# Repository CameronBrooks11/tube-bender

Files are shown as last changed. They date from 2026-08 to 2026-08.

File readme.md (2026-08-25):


# Tube-bender
A parametric manual rotary-draw tube bender, from 1/8 in to 2 in outside diameter.

The machine is the swing-arm pattern that J D Squared and Pro-Tools have sold for
decades: a grooved forming die on a centre pivot, a U-strap clamping the tube to it, a
followbar reacting the bending load, and a drive link that rotates the die from a
handle. What is new here is that it is derived rather than drawn - the die comes from
the tube, the pins come from the loads they carry, and the base bolt pattern comes from
the torque it has to react.

Every part of the working mechanism is built and derived: the forming die - machined
from one plate or stacked from flat-cut slices, behind the same interface - its plates,
the clamp, the followbar, the tapered frame and drive links, the die lock that holds the
die against springback between strokes, and a bench base or a pedestal.

## Driving it

Open this file in OpenSCAD and use the **Customizer** (Window > Customizer). Everything
that decides what the machine is has a control there: the tube, the bend, the plate
stock, the die style, the mounting, and which part to look at. `tube_bender.json` beside
this file carries a few worked configurations to start from, including the 1-1/2 in
prototype and a sliced-die build for a shop with no mill.

The **Units** tab switches the report and the BOM between metric and imperial as a
whole system - length, force, moment, stress and mass together, because inches with
newtons is harder to check than either on its own. It changes nothing that is
calculated, and it changes no name: a tube is "1-1/2 in OD x 0.095 in wall" and plate is
ordered as "1/4 in" in both.

Nothing in the Customizer is a dimension of a part. Every part is derived from the tube
and the loads, so choosing a 1 in tube resizes the die, the pins, the links, the base
and the handle together - and the arithmetic behind that is echoed rather than hidden.
`just report` prints it, or read the console after any render.

## Two words in the parts list that are NopSCADlib's, not ours

Nothing here is printed. The list has a **"3D printed parts"** heading because that is
what NopSCADlib calls a part you make rather than buy, and under it are the three parts
with real depth to cut - the forming die, the clamp and the followbar - which are
**machined**. Everything flat is under **"CNC routed"**, which is right: those go to a
laser, waterjet or plasma table as the DXF files linked beside them.

Why the numbers are what they are, and what each one rests on, is in
[docs/design-basis.md](docs/design-basis.md). What the Onshape prototype this was
started from actually measured, and which of its features survived, is in
[docs/reverse-engineering.md](docs/reverse-engineering.md).

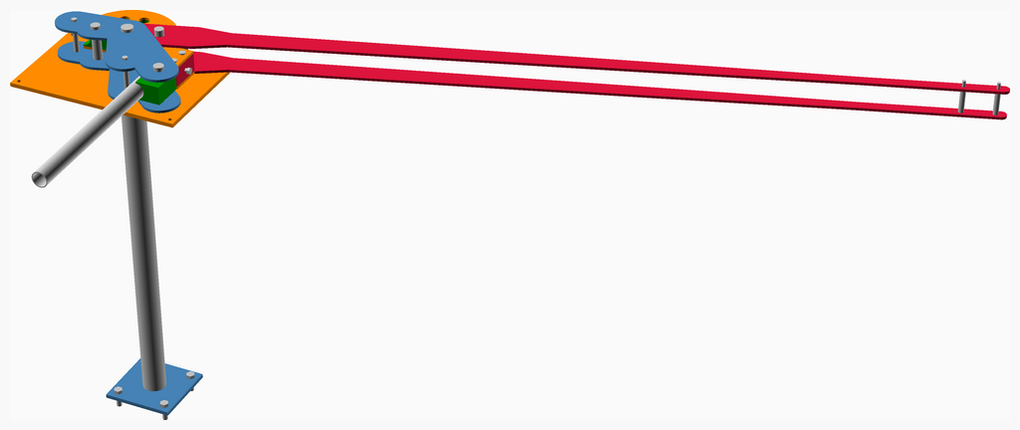
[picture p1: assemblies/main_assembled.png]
Main Assembly


<span></span>

---
## Table of Contents
1. [Parts list](#Parts_list)
1. [Base Assembly](#base_assembly)
1. [Die Assembly](#die_assembly)
1. [Handle Assembly](#handle_assembly)
1. [Main Assembly](#main_assembly)

<span></span>
[Top](#TOP)

---

## Parts list
| <span style="writing-mode: vertical-rl; text-orientation: mixed;">Base</span> | <span style="writing-mode: vertical-rl; text-orientation: mixed;">Die</span> | <span style="writing-mode: vertical-rl; text-orientation: mixed;">Handle</span> | <span style="writing-mode: vertical-rl; text-orientation: mixed;">Main</span> | <span style="writing-mode: vertical-rl; text-orientation: mixed;">TOTALS</span> |  |
|---:|---:|---:|---:|---:|:---|
|  |  |  |  | | **Vitamins** |
| &nbsp;&nbsp;.&nbsp; | &nbsp;&nbsp;.&nbsp; | &nbsp;&nbsp;.&nbsp; | &nbsp;&nbsp;4&nbsp; |  &nbsp;&nbsp;4&nbsp; | &nbsp;&nbsp; Bolt hex head 1/2 in x 44.45 mm, with nut and washers, NO ORDER NUMBER - this row is a hole in the BOM |
| &nbsp;&nbsp;.&nbsp; | &nbsp;&nbsp;.&nbsp; | &nbsp;&nbsp;.&nbsp; | &nbsp;&nbsp;1&nbsp; |  &nbsp;&nbsp;1&nbsp; | &nbsp;&nbsp; Bolt hex head 3/8 in x 38.1 mm, with nut and washers, NO ORDER NUMBER - this row is a hole in the BOM |
| &nbsp;&nbsp;.&nbsp; | &nbsp;&nbsp;6&nbsp; | &nbsp;&nbsp;.&nbsp; | &nbsp;&nbsp;.&nbsp; |  &nbsp;&nbsp;6&nbsp; | &nbsp;&nbsp; Bolt hex head 3/8 in x 57.15 mm, with nut and washers, NO ORDER NUMBER - this row is a hole in the BOM |
| &nbsp;&nbsp;.&nbsp; | &nbsp;&nbsp;.&nbsp; | &nbsp;&nbsp;.&nbsp; | &nbsp;&nbsp;2&nbsp; |  &nbsp;&nbsp;2&nbsp; | &nbsp;&nbsp; Bolt hex head 5/16 in x 127 mm, with nut and washers, NO ORDER NUMBER - this row is a hole in the BOM |
| &nbsp;&nbsp;.&nbsp; | &nbsp;&nbsp;.&nbsp; | &nbsp;&nbsp;.&nbsp; | &nbsp;&nbsp;1&nbsp; |  &nbsp;&nbsp;1&nbsp; | &nbsp;&nbsp; Pin clevis 1-1/8 in dia x 88.9 mm usable, seats on the base plate, NO ORDER NUMBER - this row is a hole in the BOM |
| &nbsp;&nbsp;.&nbsp; | &nbsp;&nbsp;.&nbsp; | &nbsp;&nbsp;.&nbsp; | &nbsp;&nbsp;1&nbsp; |  &nbsp;&nbsp;1&nbsp; | &nbsp;&nbsp; Pin clevis 3/4 in dia x 88.9 mm usable, seats on the base plate, 98306A868 |
| &nbsp;&nbsp;.&nbsp; | &nbsp;&nbsp;.&nbsp; | &nbsp;&nbsp;2&nbsp; | &nbsp;&nbsp;.&nbsp; |  &nbsp;&nbsp;2&nbsp; | &nbsp;&nbsp; Pin clevis 5/16 in dia x 82.55 mm usable, NO ORDER NUMBER - this row is a hole in the BOM |
| &nbsp;&nbsp;.&nbsp; | &nbsp;&nbsp;.&nbsp; | &nbsp;&nbsp;.&nbsp; | &nbsp;&nbsp;2&nbsp; |  &nbsp;&nbsp;2&nbsp; | &nbsp;&nbsp; Pin clevis 5/8 in dia x 57.15 mm usable, NO ORDER NUMBER - this row is a hole in the BOM |
| &nbsp;&nbsp;.&nbsp; | &nbsp;&nbsp;.&nbsp; | &nbsp;&nbsp;.&nbsp; | &nbsp;&nbsp;1&nbsp; |  &nbsp;&nbsp;1&nbsp; | &nbsp;&nbsp; Pin clevis 7/8 in dia x 82.55 mm usable, NO ORDER NUMBER - this row is a hole in the BOM |
| &nbsp;&nbsp;.&nbsp; | &nbsp;&nbsp;.&nbsp; | &nbsp;&nbsp;.&nbsp; | &nbsp;&nbsp;1&nbsp; |  &nbsp;&nbsp;1&nbsp; | &nbsp;&nbsp; Pin clevis 7/8 in dia x 88.9 mm usable, seats on the base plate, NO ORDER NUMBER - this row is a hole in the BOM |
| &nbsp;&nbsp;.&nbsp; | &nbsp;&nbsp;1&nbsp; | &nbsp;&nbsp;.&nbsp; | &nbsp;&nbsp;.&nbsp; |  &nbsp;&nbsp;1&nbsp; | &nbsp;&nbsp; Plate mild steel 1-3/4 in, blank 228.6 x 190.5 mm, faced to 44.45 mm |
| &nbsp;&nbsp;.&nbsp; | &nbsp;&nbsp;.&nbsp; | &nbsp;&nbsp;.&nbsp; | &nbsp;&nbsp;1&nbsp; |  &nbsp;&nbsp;1&nbsp; | &nbsp;&nbsp; Plate mild steel 1-3/4 in, blank 54.37 x 76.2 mm, faced to 44.45 mm |
| &nbsp;&nbsp;.&nbsp; | &nbsp;&nbsp;.&nbsp; | &nbsp;&nbsp;.&nbsp; | &nbsp;&nbsp;1&nbsp; |  &nbsp;&nbsp;1&nbsp; | &nbsp;&nbsp; Plate mild steel 1-3/4 in, blank 57.55 x 76.2 mm, faced to 44.45 mm |
| &nbsp;&nbsp;.&nbsp; | &nbsp;&nbsp;.&nbsp; | &nbsp;&nbsp;2&nbsp; | &nbsp;&nbsp;.&nbsp; |  &nbsp;&nbsp;2&nbsp; | &nbsp;&nbsp; Plate mild steel 1/4 in, blank 2034.1 x 86.93 mm |
| &nbsp;&nbsp;.&nbsp; | &nbsp;&nbsp;2&nbsp; | &nbsp;&nbsp;.&nbsp; | &nbsp;&nbsp;.&nbsp; |  &nbsp;&nbsp;2&nbsp; | &nbsp;&nbsp; Plate mild steel 1/4 in, blank 228.6 x 190.5 mm |
| &nbsp;&nbsp;1&nbsp; | &nbsp;&nbsp;.&nbsp; | &nbsp;&nbsp;.&nbsp; | &nbsp;&nbsp;1&nbsp; |  &nbsp;&nbsp;2&nbsp; | &nbsp;&nbsp; Plate mild steel 1/4 in, blank 368.73 x 210.75 mm |
| &nbsp;&nbsp;1&nbsp; | &nbsp;&nbsp;.&nbsp; | &nbsp;&nbsp;.&nbsp; | &nbsp;&nbsp;.&nbsp; |  &nbsp;&nbsp;1&nbsp; | &nbsp;&nbsp; Plate mild steel 3/8 in, blank 171.45 x 171.45 mm |
| &nbsp;&nbsp;1&nbsp; | &nbsp;&nbsp;.&nbsp; | &nbsp;&nbsp;.&nbsp; | &nbsp;&nbsp;.&nbsp; |  &nbsp;&nbsp;1&nbsp; | &nbsp;&nbsp; Plate mild steel 3/8 in, blank 416.59 x 258.61 mm |
| &nbsp;&nbsp;.&nbsp; | &nbsp;&nbsp;.&nbsp; | &nbsp;&nbsp;.&nbsp; | &nbsp;&nbsp;1&nbsp; |  &nbsp;&nbsp;1&nbsp; | &nbsp;&nbsp; Tube 1-1/2 in OD x 0.095 in wall, ASTM A513 Type 1 ERW mild steel, as-welded, length 600 mm |
| &nbsp;&nbsp;.&nbsp; | &nbsp;&nbsp;.&nbsp; | &nbsp;&nbsp;2&nbsp; | &nbsp;&nbsp;.&nbsp; |  &nbsp;&nbsp;2&nbsp; | &nbsp;&nbsp; Tube 1/2 in OD x 0.065 in wall, mild steel, length 58.15 mm |
| &nbsp;&nbsp;.&nbsp; | &nbsp;&nbsp;.&nbsp; | &nbsp;&nbsp;.&nbsp; | &nbsp;&nbsp;2&nbsp; |  &nbsp;&nbsp;2&nbsp; | &nbsp;&nbsp; Tube 1/2 in OD x 0.065 in wall, mild steel, length 71.85 mm |
| &nbsp;&nbsp;1&nbsp; | &nbsp;&nbsp;.&nbsp; | &nbsp;&nbsp;.&nbsp; | &nbsp;&nbsp;.&nbsp; |  &nbsp;&nbsp;1&nbsp; | &nbsp;&nbsp; Tube 2-1/4 in OD x 0.120 in wall, mild steel, length 898.2 mm |
| &nbsp;&nbsp;4&nbsp; | &nbsp;&nbsp;9&nbsp; | &nbsp;&nbsp;6&nbsp; | &nbsp;&nbsp;19&nbsp; | &nbsp;&nbsp;38&nbsp; | &nbsp;&nbsp;Total vitamins count |
|  |  |  |  | | **3D printed parts** |
| &nbsp;&nbsp;.&nbsp; | &nbsp;&nbsp;.&nbsp; | &nbsp;&nbsp;.&nbsp; | &nbsp;&nbsp;1&nbsp; |  &nbsp;&nbsp;1&nbsp; | &nbsp;&nbsp;clamp.stl |
| &nbsp;&nbsp;.&nbsp; | &nbsp;&nbsp;.&nbsp; | &nbsp;&nbsp;.&nbsp; | &nbsp;&nbsp;1&nbsp; |  &nbsp;&nbsp;1&nbsp; | &nbsp;&nbsp;followbar.stl |
| &nbsp;&nbsp;.&nbsp; | &nbsp;&nbsp;1&nbsp; | &nbsp;&nbsp;.&nbsp; | &nbsp;&nbsp;.&nbsp; |  &nbsp;&nbsp;1&nbsp; | &nbsp;&nbsp;forming_die.stl |
| &nbsp;&nbsp;.&nbsp; | &nbsp;&nbsp;1&nbsp; | &nbsp;&nbsp;.&nbsp; | &nbsp;&nbsp;2&nbsp; | &nbsp;&nbsp;3&nbsp; | &nbsp;&nbsp;Total 3D printed parts count |
|  |  |  |  | | **CNC routed parts** |
| &nbsp;&nbsp;1&nbsp; | &nbsp;&nbsp;.&nbsp; | &nbsp;&nbsp;.&nbsp; | &nbsp;&nbsp;.&nbsp; |  &nbsp;&nbsp;1&nbsp; | &nbsp;&nbsp;base.dxf |
| &nbsp;&nbsp;.&nbsp; | &nbsp;&nbsp;2&nbsp; | &nbsp;&nbsp;.&nbsp; | &nbsp;&nbsp;.&nbsp; |  &nbsp;&nbsp;2&nbsp; | &nbsp;&nbsp;die_plate.dxf |
| &nbsp;&nbsp;.&nbsp; | &nbsp;&nbsp;.&nbsp; | &nbsp;&nbsp;2&nbsp; | &nbsp;&nbsp;.&nbsp; |  &nbsp;&nbsp;2&nbsp; | &nbsp;&nbsp;drive_link.dxf |
| &nbsp;&nbsp;1&nbsp; | &nbsp;&nbsp;.&nbsp; | &nbsp;&nbsp;.&nbsp; | &nbsp;&nbsp;1&nbsp; |  &nbsp;&nbsp;2&nbsp; | &nbsp;&nbsp;frame_link.dxf |
| &nbsp;&nbsp;1&nbsp; | &nbsp;&nbsp;.&nbsp; | &nbsp;&nbsp;.&nbsp; | &nbsp;&nbsp;.&nbsp; |  &nbsp;&nbsp;1&nbsp; | &nbsp;&nbsp;pedestal_foot.dxf |
| &nbsp;&nbsp;3&nbsp; | &nbsp;&nbsp;2&nbsp; | &nbsp;&nbsp;2&nbsp; | &nbsp;&nbsp;1&nbsp; | &nbsp;&nbsp;8&nbsp; | &nbsp;&nbsp;Total CNC routed parts count |

<span></span>
[Top](#TOP)

---

## Base Assembly
### Vitamins
|Qty|Description|
|---:|:---|
|1| Plate mild steel 1/4 in, blank 368.73 x 210.75 mm|
|1| Plate mild steel 3/8 in, blank 171.45 x 171.45 mm|
|1| Plate mild steel 3/8 in, blank 416.59 x 258.61 mm|
|1| Tube 2-1/4 in OD x 0.120 in wall, mild steel, length 898.2 mm|

### CNC Routed parts

| 1 x [base.dxf](dxfs/base.dxf) | 1 x [frame_link.dxf](dxfs/frame_link.dxf) | 1 x [pedestal_foot.dxf](dxfs/pedestal_foot.dxf) |
|---|---|---|
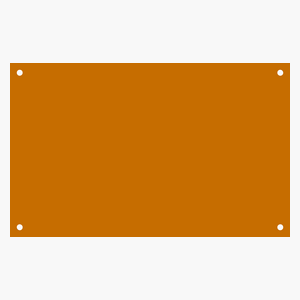
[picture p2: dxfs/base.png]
base.dxf
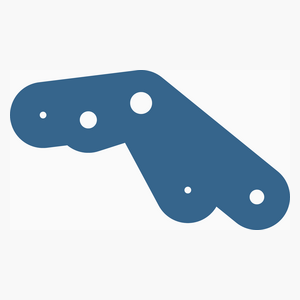
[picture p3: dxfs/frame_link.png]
frame_link.dxf
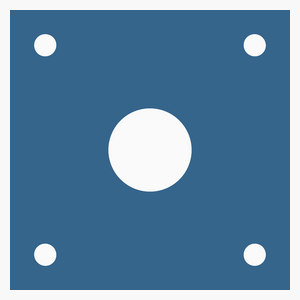
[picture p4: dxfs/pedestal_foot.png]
pedestal_foot.dxf
|  |  |  

### Assembly instructions
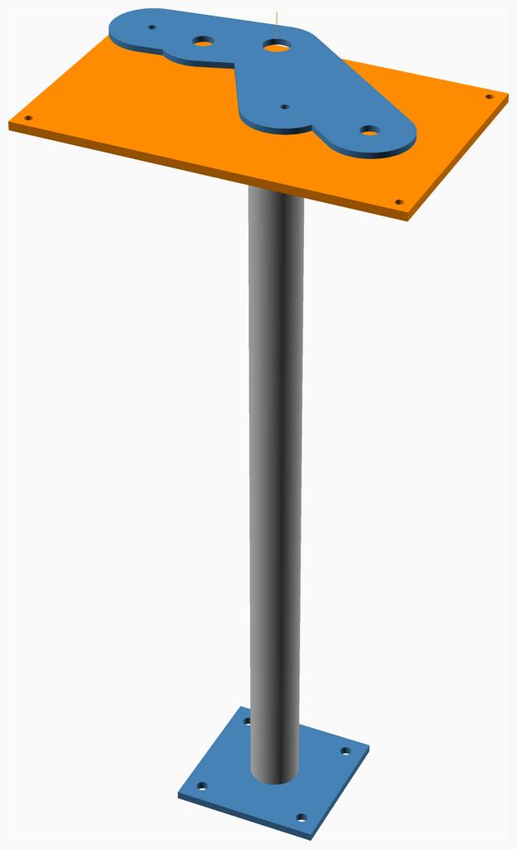
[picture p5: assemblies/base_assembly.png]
base_assembly


**Stage 1 - the base weldment.** The lower frame link is welded flat to the base plate,
and this is the joint the whole drive torque leaves through, so it is worth getting
right before anything else exists to be in the way.

Fillet **both edges** of the link where it lands on the plate, everywhere it lands - the
run from the pivot to the followbar eye is what the report sizes, and the lock and tie
arms want the same bead round them. The plate is cut to the link's own outline plus a
margin, so if an arm is hanging over an edge something has gone wrong before the welder
got here. The leg is not written here on purpose - it is a
function of the plate you chose, so `just report` is where it lives and a number in this
sentence would be a lie for every configuration but one. It comes out at the code
minimum for every size in the range, with a factor of about six in hand on the load, so
what to be careful about is fusion and distortion rather than size. Tack both ends,
check the link is still flat and still square to the plate, then run it.

On a pedestal build the post is welded to the underside of the plate at the same
setting, and to its foot at the other end. Both are a ring of fillet round the post's
outside diameter; the bore in the foot is there so a second pass can be run inside it.
Those two ARE load-sized rather than minimum-sized - the report says which - so they
want a real bead, not a tack.

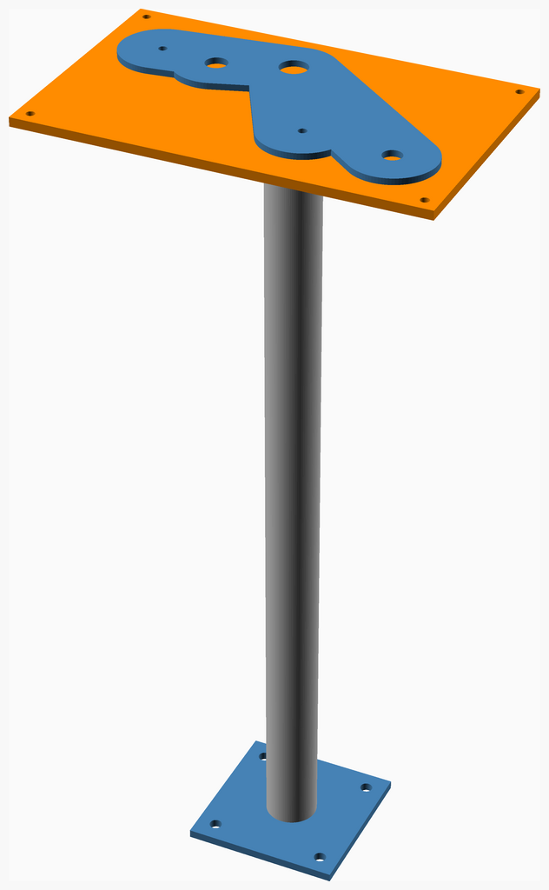
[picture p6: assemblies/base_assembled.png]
base_assembled


<span></span>
[Top](#TOP)

---

## Die Assembly
### Vitamins
|Qty|Description|
|---:|:---|
|6| Bolt hex head 3/8 in x 57.15 mm, with nut and washers, NO ORDER NUMBER - this row is a hole in the BOM|
|1| Plate mild steel 1-3/4 in, blank 228.6 x 190.5 mm, faced to 44.45 mm|
|2| Plate mild steel 1/4 in, blank 228.6 x 190.5 mm|

### 3D Printed parts

| 1 x [forming_die.stl](stls/forming_die.stl) |
|---|
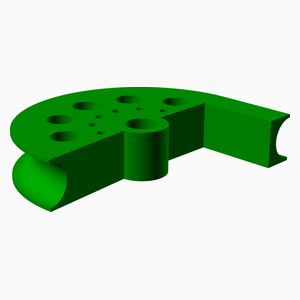
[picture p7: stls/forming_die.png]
forming_die.stl
|  

### CNC Routed parts

| 2 x [die_plate.dxf](dxfs/die_plate.dxf) |
|---|
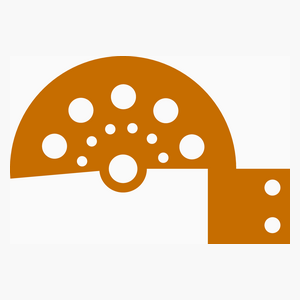
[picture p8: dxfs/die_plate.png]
die_plate.dxf
|  

### Assembly instructions
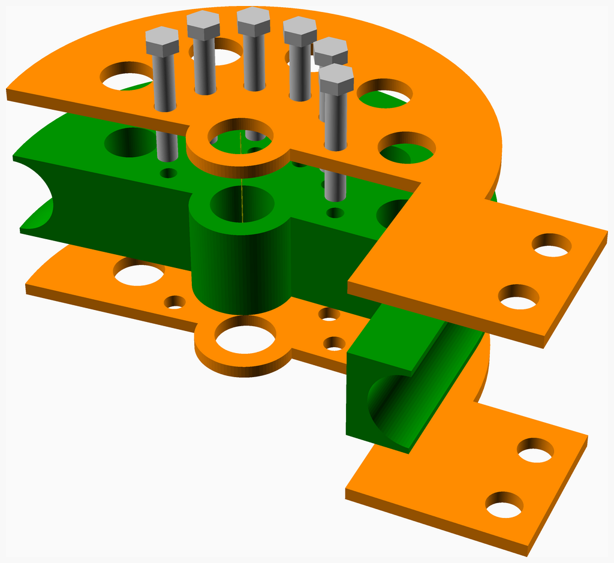
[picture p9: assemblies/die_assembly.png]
die_assembly


**Stage 2 - the die.** The two die plates bolt to the faces of the forming die and never
come off again. They are what the clamp pins to, so their tails have to line up with
each other: bolt one on, use it to spot the other, and check the two tails are parallel
before anything is tightened.

The bolts sit on a circle between the hub and the drive holes. The report gives the
shear in each against its allowable; they carry the clamp's whole drag on the tube plus
the moment that drag makes about the pivot, so they are not incidental fixings.

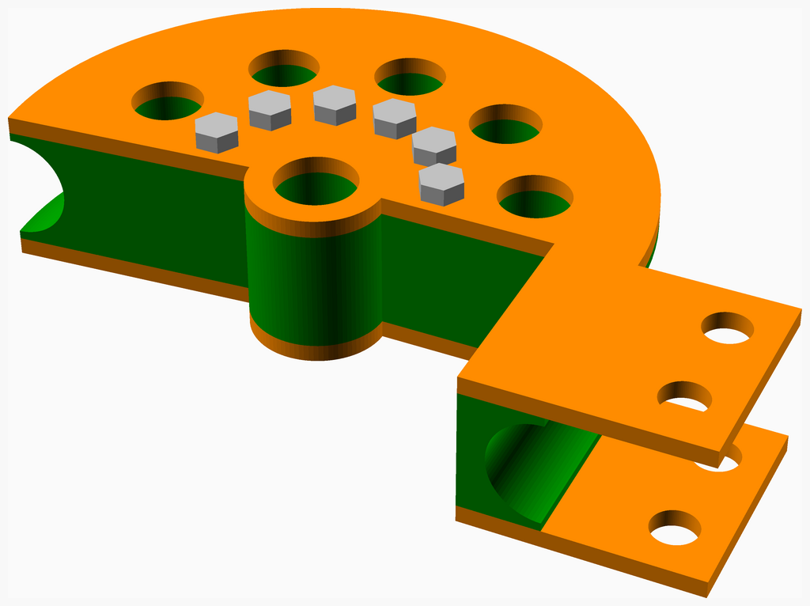
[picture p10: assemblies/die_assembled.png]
die_assembled


<span></span>
[Top](#TOP)

---

## Handle Assembly
### Vitamins
|Qty|Description|
|---:|:---|
|2| Pin clevis 5/16 in dia x 82.55 mm usable, NO ORDER NUMBER - this row is a hole in the BOM|
|2| Plate mild steel 1/4 in, blank 2034.1 x 86.93 mm|
|2| Tube 1/2 in OD x 0.065 in wall, mild steel, length 58.15 mm|

### CNC Routed parts

| 2 x [drive_link.dxf](dxfs/drive_link.dxf) |
|---|
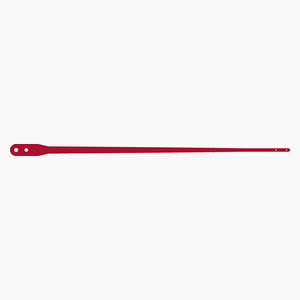
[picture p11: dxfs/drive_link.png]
drive_link.dxf
|  

### Assembly instructions
handle_assembly

**Stage 3 - the handle.** The two drive links are joined by the two spacer bolts at the
grip, each running through a length of tube that sets the gap and stops the pair being
pulled together when the bolts are done up. Without those tubes the bolts close the fork
and the die will not go in.

Join them at the grip end only. The pivot end has to stay open, because that is where
the die assembly slides in at the next stage.

handle_assembled

<span></span>
[Top](#TOP)

---

## Main Assembly
### Vitamins
|Qty|Description|
|---:|:---|
|4| Bolt hex head 1/2 in x 44.45 mm, with nut and washers, NO ORDER NUMBER - this row is a hole in the BOM|
|1| Bolt hex head 3/8 in x 38.1 mm, with nut and washers, NO ORDER NUMBER - this row is a hole in the BOM|
|2| Bolt hex head 5/16 in x 127 mm, with nut and washers, NO ORDER NUMBER - this row is a hole in the BOM|
|1| Pin clevis 1-1/8 in dia x 88.9 mm usable, seats on the base plate, NO ORDER NUMBER - this row is a hole in the BOM|
|1| Pin clevis 3/4 in dia x 88.9 mm usable, seats on the base plate, 98306A868|
|2| Pin clevis 5/8 in dia x 57.15 mm usable, NO ORDER NUMBER - this row is a hole in the BOM|
|1| Pin clevis 7/8 in dia x 82.55 mm usable, NO ORDER NUMBER - this row is a hole in the BOM|
|1| Pin clevis 7/8 in dia x 88.9 mm usable, seats on the base plate, NO ORDER NUMBER - this row is a hole in the BOM|
|1| Plate mild steel 1-3/4 in, blank 54.37 x 76.2 mm, faced to 44.45 mm|
|1| Plate mild steel 1-3/4 in, blank 57.55 x 76.2 mm, faced to 44.45 mm|
|1| Plate mild steel 1/4 in, blank 368.73 x 210.75 mm|
|1| Tube 1-1/2 in OD x 0.095 in wall, ASTM A513 Type 1 ERW mild steel, as-welded, length 600 mm|
|2| Tube 1/2 in OD x 0.065 in wall, mild steel, length 71.85 mm|

### 3D Printed parts

| 1 x [clamp.stl](stls/clamp.stl) | 1 x [followbar.stl](stls/followbar.stl) |
|---|---|
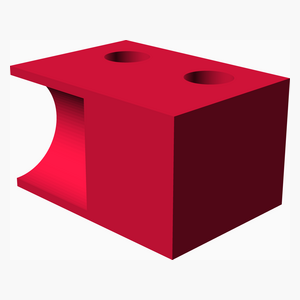
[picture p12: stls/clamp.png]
clamp.stl
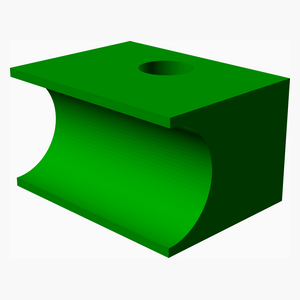
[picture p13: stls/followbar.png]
followbar.stl
|  |  

### CNC Routed parts

| 1 x [frame_link.dxf](dxfs/frame_link.dxf) |
|---|
| frame_link.dxf 

### Sub-assemblies

| 1 x base_assembly | 1 x die_assembly | 1 x handle_assembly |
|---|---|---|
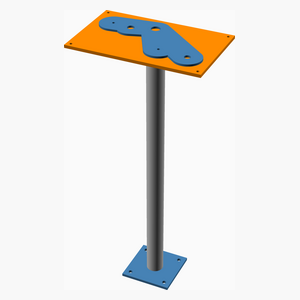
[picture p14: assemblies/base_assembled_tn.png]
base_assembled
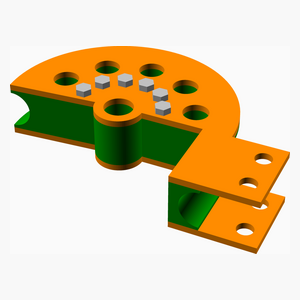
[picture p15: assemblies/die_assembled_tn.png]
die_assembled
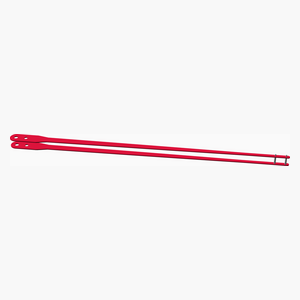
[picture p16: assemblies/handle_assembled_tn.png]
handle_assembled
|  |  |  

### Assembly instructions
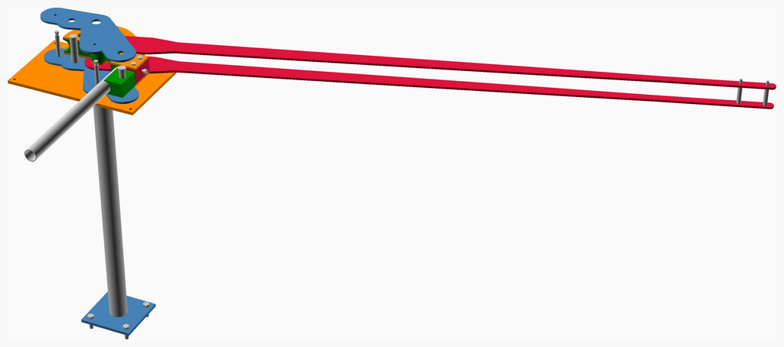
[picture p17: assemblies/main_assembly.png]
main_assembly


**Stage 4 - the machine.** Everything stacks bottom up on the base weldment, in the
order the stack itself is in: lower drive link, die assembly, upper drive link, upper
frame link.

The handle pair is a fork joined only at its far end, so the die assembly slides into it
from the pivot end rather than being lowered in. Line the two up, drop the frame pin
through the lot, and fit its retainer at the top.

Then the followbar, on its own pin between the frame links; the clamp, pinned to the die
plates' tails with its bolt left slack until a tube is in; and the die lock pin, which
goes in from the top through whichever drive hole has come round under it.

**Every pin drops in head up and nothing retains it** - no cotters, no clips. That is the
reference machine's answer, not a shortcut: searched end to end, its manual has no
retainer of any kind on any pin [JD2-M32]. It works because every hole here is vertical
and the die turns about a vertical axis, so a pin that is upright at the start of a bend
is upright at the end. And it has to work that way, because all of them come out - the
frame pin to change a die, the drive pin at every stroke, the lock pin by hand.

The frame, followbar and lock pins land on the base plate. The drive, U-strap and spacer
pins hang in the stack, where the head is the only thing holding them up.

**The frame ties go in before the pins do.** Two bolts down through the upper frame link,
a spacer tube, the lower link and the base plate, to nuts underneath. The TUBE is what
sets the gap, so they can be pulled up hard without pinching the die and the drive links
between the frame plates - and they have to be pulled up hard, because they are what makes
the frame a frame. Without them the top plate is resting on three loose pins and comes off
with the first one you pull.

Copy the reference machine's order exactly, because it is a good one: **ties hand tight,
pins in, then tighten the ties** - "as tightly as possible, while insuring the two pins
are perfectly vertical and slide easily through their respective holes" [JD2-M32 p.1].
The pins are the gauge. A pin that binds once the ties are down means the plates are not
parallel, and it is much easier to find out now than after the die is in.

Last, bolt it down: on a bench, the four anchor bolts at the base plate's corners, heads
up, down through the mounting surface to nuts underneath; on a pedestal, the four bolts
through the foot, because the base plate is welded to the post and the corner holes go to
nothing. **Do not use the machine before those are in.** They are the only thing reacting
the drive torque, and everything above them is sized on the assumption that the base does
not move.

Take the pins as the alignment gauge while you tighten them, which is JD2's own
procedure and worth copying exactly: bolts hand tight, pins in, then "tighten the nuts
as tightly as possible, while insuring the two pins are perfectly vertical and slide
easily through their respective holes" [JD2-M32 p.1]. A pin that binds after the bolts
are pulled down means the plate is not flat, and that is much easier to fix now.

And before every bend, from the same manual: **make sure all pins are completely seated
in their holes.** Their words for why - "failure to do this may cause damage to the
bender links or worse yet the operator may slip and fall".

main_assembled

<span></span>
[Top](#TOP)

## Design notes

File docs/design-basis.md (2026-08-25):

# Design basis

Why this machine is shaped the way it is, and where each number comes from. Every
quantity here is one of four kinds, and which kind it is travels with it:

- **measured** — a source states it for this exact thing
- **catalogued** — it is what you can actually buy, read off a vendor's list
- **derived** — computed from the geometry or from a stated model
- **reasoned, not cited** — nothing found supports it and the model needs a value anyway

Sources are in [`references.md`](references.md); what the Onshape original measured, and
which of its features survive, is in [`reverse-engineering.md`](reverse-engineering.md).

---

## 1. What this is

A manual rotary-draw tube bender of the swing-arm pattern: a grooved forming die on a
centre pivot, a clamp strapping the tube to the die, a followbar (pressure die) reacting
the bending load, and a drive link that rotates the die from a handle.

The vocabulary is the trade's, not invented here — **forming die**, **U-strap**,
**followbar**, **drive link**, **frame link**, **drive holes** — taken from the J D Squared
Model 32 manual [JD2-M32]. Using their names means a builder can read either document.

## 2. Tube, not pipe

Tube is specified by **outside diameter and wall thickness**; pipe is specified by a
nominal size that is neither its OD nor its ID, plus a schedule [JD2-M32 p.4]. This model
is parametric on tube OD. Pipe is supported the way the trade supports it: by looking up
the pipe's real OD and treating it as a tube of that OD.

The die must match the tube. A 1-1/2 in tube in a 1-5/8 in die set damages the followbar
[JD2-M32 p.4]. That is an assert, not an echo.

## 3. Size range: 1/8 in to 2 in OD

**Lower bound 1/8 in (3.175 mm)** — catalogued. It is the smallest tube the Swagelok hand
bender covers [SWAGELOK-MS-13-43], and below it tube becomes capillary and bending stops
being a fabrication operation.

**Upper bound 2 in (50.8 mm)** — catalogued and derived, agreeing. Both reference manual
machines stop there: the Pro-Tools 105 is rated 1/2 to 2 in OD [PROTOOLS-105] and the JD2
Model 32 is rated 1/2 to 2 in x 0.120 in wall [JD2-M32]. The derivation in §6 puts the
handle for 2 in x 0.120 in ERW at **4.4 m**, which is not a hand tool. Above 2 in the
mode of actuation changes rather than the size merely growing.

Neither bound is a limit of the geometry — the model will draw a 3 in die. They are the
band in which a *manual* machine is the right answer, and the model reports when a
configuration leaves it rather than refusing to draw it.

## 4. Centreline radius: minimum 3 x OD

CLR is stated as **D of bend**, `Fd = R / T` — centreline radius over tube OD
[BENDTOOLING]. Its companion is **wall factor**, `Fw = T / W` — OD over wall thickness.
Both are ratios; a larger `Fd` and a smaller `Fw` each make a bend easier
[BENDTOOLING, PROTOOLS-WALLFACTOR].

Note the direction, because secondary sources get it backwards: wall factor is
**OD divided by wall**, so *thin wall = high wall factor = harder*. One trade-press
summary read during this research stated it inverted.

**The rule this model adopts: minimum CLR = 3 x OD.** It is the industry rule of thumb for
bending without an internal mandrel [PROTOOLS-WALLFACTOR, THEFABRICATOR-4MODES], and this
machine has no mandrel. Below 3D a mandrel becomes worth considering; below 2D one is
generally required, and unsupported tube ovalises and wrinkles [ROGUEFAB-MANDREL].

Sanity-checked against what is actually sold. Pro-Tools' own round-die matrix
[PROTOOLS-DIES] runs:

| OD | CLRs offered | D of bend |
|---|---|---|
| 3/4 | 3, 3-1/2 | 4.0 – 4.7 |
| 1 | 3, 3-1/2, 4, 4-1/2 | 3.0 – 4.5 |
| 1-1/4 | 4, 4-1/2, 5, 6 | 3.2 – 4.8 |
| 1-1/2 | 4-1/2, 5, 6, 7 | 3.0 – 4.7 |
| 2 | 6, 7 | 3.0 – 3.5 |
| 2-1/2 | 7 | 2.8 |

Every entry sits between 2.8D and 4.8D, clustered on 3–4.5D.

**The small end does not agree, and the disagreement is real.** The Swagelok hand bender's
fixed radii are 0.56 in on 1/8 in tube (4.5D), 0.56 **and 0.75** in on 1/4 in (2.25D and
3.0D), 0.94 in on 5/16 in (3.0D), 0.94 in on 3/8 in (**2.5D, and it is the only radius
offered**) and 1.5 in on 1/2 in (3.0D) [SWAGELOK-MS-13-43]. So at 1/4 in and 3/8 in the
trade routinely bends tighter than 3D, and at 3/8 in there is nothing else on offer.

That is not a reason to move the floor. The 3D rule is about ovality and wrinkling in the
unsupported span of a large tube, and thin instrumentation tube in a hand bender's fully
enclosing groove is a different problem. But it does mean the floor is **reported, not
enforced**, at the bottom of the range: `bend_departures()` distinguishes "you chose a
radius nobody sells" from "every radius sold for this OD is tighter than 3 x OD", because
those call for opposite responses.

An earlier draft of this section quoted only the 3.0D options from the same table and
concluded the small end agreed. It does not. The sweep in `just check-sizes` is what
surfaced it.

So `clr_min = 3 * od` is a floor the whole industry sits on or just above, and the model
**echoes the D of bend and names it when it falls below 3**, rather than refusing — a
thick-wall DOM tube at 2.8D is a real bend that real people make.

**Default CLR** is the smallest catalogued radius at or above 3D for the selected tube,
because a die you can buy is worth more than a die you have to justify.

## 5. The forming die groove is not a half-round

This is the finding that most changes the part. A production forming die's groove is
machined to a profile such that **the tube does not fully seat in it**:

> "If you lay a section of tubing into the forming die you will notice that it will NOT
> completely seat into the die's groove. This is normal for tube size dies and becomes
> very important as the tube's wall thickness gets thinner." — [JD2-M32 p.4]

The profile exists to resist flattening on the outside of the bend. Pipe dies, being
thicker-walled and more forgiving, do let the pipe seat fully.

The followbar carries the same idea: its rear insert is **angled** relative to the tube
axis, "calculated and machined into the backing block to 1/1000 of a degree from
theoretically perfect for the tube size and bend radius", to support the tube just past
the point of bend [JD2-M32 p.5]. And the followbar's grooves ride *slightly lower* than
the die's groove so the followbar can rise under load rather than bind [JD2-M32 p.5].

**A withdrawn claim.** An earlier draft of this section also stated that the part line
sits on the tube centreline with the bend die containing 50 % of the tube and the clamp
and pressure die grooves somewhat less, cited to a tooling vendor's design page. That page
was then retrieved and **does not contain it** — it carries die materials and hardness and
nothing about groove depth. The statement came from a search summary that had blended
sources. It is removed rather than re-attributed, because the only honest position is that
**no source read here specifies the bend die's groove profile**.

**Decision.** v1 cuts a true half-round groove of radius `od/2` and exposes a
`groove_seat` factor plus a followbar drop, both defaulting to a plain fit, with the
non-circular profile and the followbar angle recorded on the roadmap. Reason: the exact
profile is proprietary, no source states it, and inventing one would be a
*reasoned, not cited* number sitting in the load path of the finished part. A plain
half-round is a known, stateable approximation; a guessed ellipse is not.

## 6. Leverage: handle length is derived from a force budget, not copied

The die's drive torque has to reach the tube's fully plastic bending moment:

```
Zp = (D^3 - d^3) / 6           plastic section modulus, round tube
Mp = sigma_y * Zp              fully plastic bending moment
L  = Mp / F_operator           handle length for a given pull
```

`Zp` for a hollow round section is standard plasticity [PLASTIC-MOMENT]. `Mp` is a
**floor**, not the answer: it ignores strain hardening, the friction of the followbar and
U-strap, and the fact that the hinge travels. The real torque is higher. The model
reports `Mp` and says so.

Yield strength is registered as the **band the standard gives**, not a single number.
ASTM A513 round tube [TOTTEN-A513]:

| condition | yield ksi | yield MPa |
|---|---|---|
| as-welded (ERW, A513 T1) | 30 – 45 | 207 – 310 |
| normalized | 23 – 40 | 159 – 276 |
| mandrel-drawn (DOM, A513 T5) | 50 – 70 | 345 – 483 |
| mandrel-drawn, stress-relieved | 45 – 65 | 310 – 448 |

**Operator force ceiling: 490 N.** That is the largest horizontal push or pull the FAA
Human Factors Design Standard allows a designer to require, and only when both hands are
used and the operator is braced against a wall or standing on non-slip ground; with
ordinary traction the ceiling is 200–310 N [HFDS-2009 Exh. 14.5.3.1]. Arm strength alone,
5th-percentile male, is about 180–200 N [HFDS-2009 Exh. 14.5.2.1].

Handle length at 490 N, taking the top of each yield band:

| OD x wall | Zp mm^3 | ERW Mp N·m | handle m | DOM Mp N·m | handle m |
|---|---|---|---|---|---|
| 1/4 x .035 | 27 | 8 | 0.02 | 13 | 0.03 |
| 1/2 x .049 | 164 | 51 | 0.10 | 79 | 0.16 |
| 3/4 x .065 | 501 | 155 | 0.32 | 242 | 0.49 |
| 1 x .065 | 933 | 289 | 0.59 | 451 | 0.92 |
| 1-1/4 x .065 | 1497 | 464 | 0.95 | 723 | 1.48 |
| 1-1/2 x .095 | 3078 | 954 | 1.95 | 1487 | 3.03 |
| 1-3/4 x .095 | 4269 | 1323 | 2.70 | 2062 | 4.21 |
| 2 x .120 | 6960 | 2158 | 4.40 | 3362 | 6.86 |

Read across the ERW column and the size range falls out of the arithmetic:

- **to 1 in** — handle under 0.75 m. A hand-held tool.
- **1-1/4 to 1-1/2 in** — 1 to 2 m. Bench- or floor-mounted, two hands, long handle.
- **1-3/4 in and up** — 2.7 m and beyond. Not a manual machine.

That is the same boundary a practitioner gave independently: handheld to roughly 1/2–1 in,
~1.5 in as the practical manual target, 2 in as the extreme for a floor-mounted
high-advantage machine, powered above.

It also puts a number on the reference machines. JD2 states a 36 in (0.914 m) handle lets
an average user bend 1-3/4 x .095 mild steel [JD2-M32 p.2]; against `Mp` that is
**1449 N of pull**, three times the HFDS design ceiling — and the same manual tells you to
cut a length of 1 in pipe for more leverage when you want it. The reference machines are
worked past the limit an ergonomics standard would let a designer specify. This model
derives the handle instead of copying theirs, and echoes the implied operator force so the
departure is visible.

## 7. Pin fits: the drive holes are meant to be sloppy

Not a defect to correct. JD2's drive holes are **1 in holes on a 7/8 in drive pin —
drilled 1/8 in oversize on purpose**, "to provide easier pin installation" [JD2-M32 p.7].
The pin is repositioned by hand every few degrees of bend; a close fit would make the
machine unusable.

So the model registers two distinct fits and names them:

- **pivot fit** — the frame pin the die and links rotate on. Close running clearance.
- **index fit** — drive holes, U-strap pin, lock pin. Deliberately oversize, default
  +1/8 in on the pin, from JD2's practice.

Dies with a CLR under 3 in have no drive holes at all — there is no room — and the
ratchet is not used for them [JD2-M32 p.4, p.7]. The model derives whether drive holes
fit rather than always drawing them.

## 8. Units: imperial identity, millimetre arithmetic

Tube is bought by imperial OD in North America and the entire die catalogue is imperial,
so **a registry row's identity is its inch size** — `3/4 in OD x 3 in CLR` is the name of a
real thing and 19.05 x 76.2 is not. Metric tube is registered the same way in its own
native sizes.

**All arithmetic is in millimetres**, because OpenSCAD and NopSCADlib are millimetre
libraries and mixing units inside the derivation is how the two halves of a dimension
drift apart. Inch values are converted once, at the registry row.

### Reading is a third thing, and it is a whole system

The derivation stays in millimetres, newtons and megapascals whatever the reader wants.
`units` converts at the last step before a number reaches a human — the report and the BOM
— and nothing upstream of that knows it exists. `scad/utils/units.scad` is the only file in
the model where a unit is ever written down.

**It moves everything together, not just lengths.** Inches with newtons is harder to check
than either system on its own: you cannot carry a sanity calculation across mixed units in
your head. So length, force, moment, stress and mass convert as a set.

There is a second reason, and it turned out to be the more useful one. Most of the sources
this model rests on are imperial-native, so reporting in imperial puts their numbers back
into the form they were published in — and **shows where a registry row is itself a rounded
conversion**, which is invisible from the metric side:

| quantity | registry holds | reported imperial | the source's own number |
|---|---|---|---|
| A513 T1 yield, top of band | 310 MPa | 44.96 ksi | **45 ksi** [TOTTEN-A513] |
| A36 plate, `0.6 Fy` | 0.6 × 250 MPa = 150 MPa | 21.76 ksi | 0.6 × **36 ksi** = 21.6 ksi |
| operator pull ceiling | 490 N | 110.2 lbf | **490 N** [HFDS-2009] |

The first row is the good case: Totten states 30–45 ksi, the registry carries the
conversion, and imperial reporting recovers 44.96 — the whole chain agreeing to the
rounding.

The second is the interesting one. `[ASTM-A36]` is recorded as **abstract**, from a vendor
page that pairs "36 ksi" with "250 MPa" — and those two are not equal. 36 ksi is 248.2 MPa,
so the registered figure is 0.7 % over the number the grade is named for, and every plate
allowance carries that. It is inside the "a real plate is stronger" margin the row already
records, and it is left alone; the point is that switching units is what made it visible.

The third is a reminder that the arrow does not always point the same way: HFDS is metric at
source, so 110.2 lbf is *ours*, not theirs. Do not read a converted number back as a
citation.

**ksi for strength, psi for bearing.** Both are stress and the trade writes them
differently because they differ by orders of magnitude: structural allowables are quoted in
ksi, what a machine bears onto a bench is quoted in psi. The base's 0.01 MPa in ksi is
0.0000015 and tells nobody anything.

### A name is not a measurement, and neither is an input

`tube_size()`, `plate_size()` and `pin_size()` return `1-1/2 in OD x 0.095 in wall`,
`1/4 in`, `7/8 in dia` — in **both** systems, because those are identities. A metric builder
still orders 1/4 in plate. Only measurements convert.

The same rule runs the other way, through the configuration. **A number you type in never
changes meaning when you change the unit system**; its unit is in its name and stays what it
says. Inputs that followed the toggle would silently reinterpret every saved configuration
the moment somebody switched, turning a 950 mm pedestal into a 24 m one. Which unit a given
input takes follows §8's rule: chosen off a catalogue means the catalogue's unit — CLR is
`clr_override_in` because every die catalogue lists 4-1/2, 5, 6, 7 — and a free dimension
takes the model's own, `pedestal_height_mm`.

### Precision is matched on resolution, not on digits

A decimal place is worth a different amount in each system: one newton is 0.22 lbf, so
integer newtons and integer pounds-force are a factor of four apart in what they resolve.
Each quantity is given whatever number of decimals puts the two within about a factor of
two, and OpenSCAD drops trailing zeros, so one rule prints `13066 N` and `2.7 N` and shows
thousandths of an inch only when a length genuinely has them.

## 9. Fabrication: one forming die now, sliced dies later

The forming die is the one part that needs real machining — a grooved disc, thickness
equal to the tube OD. v1 draws it as a single CNC-machined part.

On the roadmap, not in v1: a **sliced die**, built from stacked laser- or waterjet-cut
plates that approximate the groove in steps. It makes the machine buildable by anyone with
access to a flat-sheet cutter, which is the larger part of the audience. It is deliberately
deferred because doing it well means a parametric, interface-driven decomposition — the
same discipline as the rest of the model — and doing it badly means a stack of plates that
does not hold a tube round.

## 10. Mounting: the base reacts a torque, not a weight

The frame has to be anchored or the machine is unusable — JD2 says only "anything rigid
enough not to twist or move during the bending operation" and drills two 3/4 in holes
[JD2-M32 p.1]. That is not a specification, so here is the free body.

The tube being bent is free at its far end, so it applies no net external load. The only
external loads are the operator's pull and the base reaction. The base must therefore
supply:

- a **moment `Mp` about the vertical pivot axis** — the full drive torque, in the plane of
  the die;
- a **force `F_operator`** equal and opposite to the pull;
- a **tipping moment `F_operator x h`**, where `h` is the height of the die plane above the
  anchor plane. On a bench-mounted plate `h` is the stack height and this term is small.
  On a pedestal it is the post height and it dominates the post's design.

Bolt shear for a two-bolt bench pattern is `Mp / s + F / 2`, `s` being the bolt spacing.
At the 490 N ceiling:

| case | Mp N·m | handle m | shear per bolt, s = 100 mm | min s for a 3/4 in A307 bolt at 4x |
|---|---|---|---|---|
| 1 x .065 ERW | 289 | 0.59 | 1.7 kN | 33 mm |
| 1-1/4 x .065 ERW | 464 | 0.95 | 2.6 kN | 53 mm |
| 1-1/2 x .095 ERW | 954 | 1.95 | 5.0 kN | 109 mm |
| 2 x .120 ERW | 2158 | 4.40 | 11.0 kN | 247 mm |

**The bolts are never the problem; the spacing and what they land in are.** A pattern that
works for 1 in tube is 3x too small at 1-1/2 in, and the loads land as bearing on whatever
the plate is bolted to — a wooden bench crushes long before a 3/4 in bolt shears.

So the base is derived, not fixed: **bolt-pattern span comes from `Mp`**, not from a
remembered hole spacing. A pedestal registers as an option whose post is sized for
`F x h` bending plus `Mp` torsion, both of which the model reports.

**Reasoned, not cited:** the 4x factor on bolt shear. Nothing found sets a factor for a
hand-operated bender, and the failure is a machine that walks across the bench rather than
a fracture, so the number is chosen for stiffness margin, not strength.

## 11. Toolchain

NopSCADlib's build system is used as intended: `assembly()` for build steps, `stl()` and
`dxf()` for made parts, `vitamin()` for bought ones, and `make_all` to generate the BOM,
the DXFs, the exploded views and the assembly manual. Its multiple-configuration support
(`config_<target>.scad`) is what carries the size range — each supported tube size is a
target with its own BOM and its own DXFs.

Two gaps in the library have to be filled locally, and both are the expected kind:

- **Fasteners stop at M8.** The library's screw registry has no imperial sizes above
  `No8` wood screws and nothing near the 3/4 in pins and bolts this machine runs on. Large
  imperial fasteners, clevis pins and the die pins are registered project-side, following
  NopSCADlib's own vitamin conventions so they land on the BOM.
- **Sheet stock stops at 8 mm aluminium.** `sheets.scad` is thin sheet for enclosures.
  Structural plate — 1/4 in and up in mild steel — is registered project-side against the
  same row shape, so `sheet_2D()`, `render_2D_sheet()` and `dxf()` work unchanged.

Costed BOMs come from `parts.py`, which `bom.py` calls per part for a price and URL. That
is where McMaster part numbers live.

## 12. The forming die

Everything about the die falls out of the tube, the CLR and the pins. Nothing about it is
a remembered dimension.

**Thickness = OD + 1/4 in.** The groove is a half-round of OD/2 on the rim, so the die has
to be at least as thick as the tube is wide; an eighth of an inch of land above and below
keeps the groove from running out tangentially at the faces. That the sum lands on a stock
plate thickness for every tube in the range — tube ODs step in eighths, and plate steps in
eighths to 1 in and quarters above — is a coincidence, but it is why the land is 1/8 in
and not 3 mm.

**Outer radius = CLR.** Not a free choice. It cannot be larger: the tube's own outer
surface is at CLR + OD/2 and the followbar has to reach it. It cannot be smaller without
cutting the groove away.

**Arc = bend angle + 5 degrees** of overbend for springback. JD2 measures 3 to 4 degrees on
1-1/2 in x 0.120 in welded mild steel and says chromoly springs back about twice as far
[JD2-M32]. The 5 is that band plus margin, on one material at one size — a die allowance,
not a prediction. Bend Tooling states outright that no effective springback formula exists
[BENDTOOLING].

**Clamp tail = `max(OD x 5 - CLR, 2 x OD)`.** Bend Tooling gives the clamp die length as
`L = t x k - r` and puts the minimum for a smooth cavity "around two times the tube
diameter" [BENDTOOLING-CLAMP]; Benderparts gives the rigidity constant a default of 2, so
`k = Kr x 2.5 = 5`, and says the same about smooth versus serrated engagement
[BENDERPARTS-FORMULAS]. The two terms are not independent: k = 5 against a floor of 2
returns exactly the floor at 3 D, 3 x OD at a 2 D bend, and the floor for anything easier.

*This corrected a real error.* The first version used a flat 3 x OD grip length, taken
from a summary of a trade article that returned 403 when it was finally fetched. Both
sources that could be read say 2. The die's tail is a third shorter for it — 76 mm rather
than 114 mm on the 1-1/2 in die — which is the difference between a rule looked up and a
rule quoted.

**Drive circle** is as large as the material allows, because the whole drive torque goes
through one pin: the hole and its web have to stay inside the groove root. Whether drive
holes fit *at all* is derived, not assumed. JD2 reaches the same conclusion by hand —
"die sets with a radius smaller than 3 in will generally not have drive holes because there
is no room to drill them" [JD2-M32] — but their pins are one size for a whole 1/2 to 2 in
machine, so their cutoff is not this one's.

At the 1-1/2 in check size the derivation returns **five drive holes**, which is what JD2
drills. That is a coincidence worth noticing rather than evidence, since the pitch is
currently the prototype's 36 degrees and the frame has not been built yet — the pitch
should equal the drive link's swing, and when the frame exists it will say so if it does
not.

**Pins are not yet derived.** The die takes the frame, drive and U-strap pin diameters as
inputs and reports the force on the drive pin (12.7 kN at 1-1/2 in) so the choice can be
checked. Sizing them needs the drive link's geometry.

## 13. Pins and links

### Bending sizes every pin on this machine, not shear

Each pin runs through a central member with an outer one either side, so it is in double
shear — and it also bends across that span. The two are checked separately because **they
do not agree**: bending asks for more than twice the diameter shear does. Sizing on shear
alone gives the 1-1/2 in machine a 3/8 in drive pin where it needs 7/8 in.

The bending model takes the pin as a simply supported beam, the central member's load `F`
at midspan and each outer member reacting `F/2` at its own centroid, so the span is
`t_centre + t_outer` and `M = F (t_centre + t_outer) / 4`. That is the standard
conservative treatment — it ignores that the load is spread across each member's thickness.

**The central member is the die *and its plates*, not the die.** The plates are bolted hard
to the die's faces, carry the same pivot bore and the same drive holes, and turn with it, so
a pin through the die is a pin through all three. Taking the die alone understated the span
by two plate thicknesses — 12.7 mm at 1-1/2 in — and bending governs every pin here, so
that is not a rounding error. `layout_central_thickness()` states it once, beside the stack
it is a fact about.

The U-strap pin is the exception and keeps the die's thickness, for a different reason: its
central member is the **clamp**, which sits *between* the plates rather than turning with
them, and the clamp is as thick as the die by construction.

Allowables are AISC allowable stress design, stated in the Engineering Journal as
"tension, Ft = 0.6Fy, and that in shear, Fv = 0.4Fy" [AISC-GOEL]. Bending uses the tension
figure; AISC allows more for a solid round, so this is deliberately conservative. Bearing
on the plates is **reported, not allowed for** — no bearing allowable was found in a source
that could be read.

### The derivation lands on the reference machines' hardware

| | derived here | JD2 Model 32 |
|---|---|---|
| drive pin at 1-1/2 in | 7/8 in | 7/8 in |
| frame pin at 2 in | **1-3/8 in** | 1-1/4 in |
| drive holes | 5 | 5 |
| drive holes below a small die | none | none below 3 in CLR |

JD2 sells one machine for the whole 1/2 to 2 in range, so their single pin size has to
cover the top of it — which is exactly where the two tables meet. That is corroboration
rather than proof, but the agreements are more than coincidence deserves.

**The frame pin no longer agrees, and the disagreement was expected.** It read 1-1/4 in
until the central member was corrected to include the die plates, and it is now one size
over the reference machine. That is not evidence against either: **JD2's die is one piece
and has no plates**, so their pin crosses a shorter span than ours by construction. The
extra size is the price of a design decision this machine made and theirs did not — the
plates that §15 shows the clamp cannot do without.

Two further conservatisms sit on the same number and were left alone. Bending uses AISC's
**tension** allowable, where a solid round is permitted more; and the drive torque is the
tube's fully plastic moment, which §6 records as a floor. Either is worth about one size in
the series. The model is not tuned to reproduce JD2 — where it lands elsewhere, that is
reported rather than corrected.

### Link widths come from the section, not from the prototype

Each link is sized on the net section at its worst hole, at `0.6 Fy` for A36 plate
[ASTM-A36]. The width solves a cubic — `w^3 - ws^2 w - d^3 = 0` — by five passes of a
contraction map, which is converged to under a hundredth of a millimetre.

The **drive link's** peak moment is not at the pivot. Cut it just outside the pivot eye and
the outboard piece carries the handle force at the handle's length and the drive pin's
force at the drive radius, and those two balance — that balance is what the machine is. The
internal moment there is zero, rising outward to a peak **at the drive hole**, which is
also the weakest section.

The **frame link** is taken as a cantilever from the pivot to the followbar. That is
conservative: the base will take some of it, but where the base grabs is not decided, and a
link sized as a cantilever cannot be made worse by adding a support.

### The force ceiling is a maximum, not a target

Taking 490 N as the design pull breaks at the small end. A 1/8 in tube needs 1.4 N·m; at
490 N that is a handle **2.8 mm long** — shorter than the machine it bolts to, so the
moment between the socket and the handle's end went negative and the link width came out
`nan`.

The handle therefore also has a floor: one hand breadth of grip beyond where it attaches,
10.0 cm at the 99th percentile male [HFDS-2009 Exh. 14.3.2.1 item 45]. Where the grip
governs, the operator pulls less than the ceiling, and the model reports **the force
actually needed** — 12 N at 1/8 in, 490 N at 1 in and above. That figure says how hard the
machine is to work, which is the more useful number.

Nothing below 1/2 in would have caught this. `just check-sizes` now drives the whole model
at every registered size rather than only the bend arithmetic, and that is what found it.

## 14. The handle is the link, and the base is four bolts

### There is no separate handle

The drive link runs the full handle length and the pair of them, joined by two spacer bolts
at the grip, is what the operator holds. That is what the prototype does, and there is a
reason worth writing down for why a bolted-on handle is worse rather than merely different:

**The moment at a handle's root is the full bending moment, whatever the handle's length.**
`F x (L - r)` with `F x L = Mp` is `Mp` for any small `r`. So a separate handle needs a root
section as big as the link's, plus a joint that carries it, plus that joint to physically
fit. At 1-1/2 in the smallest registered tube whose bore clears the link pair is a 3 in
member weighing 15 kg — the same as the plate pair it would replace. The joint buys nothing
and costs a joint.

What it does cost is mass: **15.6 kg of handle** at 1-1/2 in, because the link is constant
width for 1.95 m and only the section at the drive hole needs to be that wide. Tapering it
is on the roadmap and would take most of that back.

### The base reacts a torque, and two bolts could not

The first attempt put two anchor bolts on the frame link's own axis, between its eyes, and
ran the drive torque out through them. It failed at both ends of the range and the sweep
said so:

- at **1/8 in** the whole frame link is 22 mm long, and after the pivot eye and the
  followbar eye there is no room left at all — the required span came out **negative**;
- at **2 in** the span the link can offer is 97 mm, which asks for a bolt **bigger than
  the series carries**.

Bigger bolts do not fix either, and they make the first one worse: a bigger bolt needs a
bigger edge distance, which eats the span, which raises the load. **The load path was
wrong, not the fastener.**

What replaced it:

- The **lower frame link is welded to the base plate.** No bolts in that joint at all.
- The frame link pair is already joined at both ends — the frame pin at the pivot, the
  followbar pin at the far end — so the two frame bolts were a third fixing on a two-point
  member.
- The torque leaves through **four anchor bolts at the base plate's corners**. Four bolts
  on a wide rectangle instead of two on a narrow one divides the shear by four and roughly
  doubles the arm at the same time.

The plate's size comes from the footprint it has to weld to and stand on, not from any
fastener, which is what breaks the circularity.

> **The second bullet was wrong, and §23 replaces it.** Those pins are plain and loose:
> they *locate* the pair, they do not *join* it. The frame bolts came back — not to react
> the torque, which is what they were wrongly sized for and rightly failed at, but to hold
> the two links at a fixed gap. The first and third bullets stand.

### Sizing anything against its own edge distance needs two passes

Choosing a bolt makes the radius it sits on **smaller**, because its edge distance comes
out of the plate. So the load goes up after the bolt is chosen, and one pass is optimistic:
a 3/8 in bolt picked against the nominal radius came out 1.6 % over its own allowable at
the radius it then had. The second pass settles it, and an assert now catches the case
where it would not.

The same shape appears in the drive pin — the die's drive radius depends on the hole, which
depends on the pin — and is handled the same way, with both passes printed so the
convergence can be judged rather than assumed.

### What the anchor bolts are not

They are not the thing that fails first. A 1/2 in bolt will not shear at these loads. What
fails first is **whatever the plate is bolted to**: the report prints the bearing pressure
and says plainly that it is fine on steel and wants checking against a bench top. A
pedestal is on the roadmap, and its post is the same section-modulus problem as everything
else here — bending from `F x h` plus torsion from `Mp`.

## 15. The followbar, and the clamp that is not built

### The followbar closes a placeholder rather than adding a parameter

Where the followbar's pin sits was carried as a placeholder from Phase 3 to Phase 4 — one
tube diameter outboard of the tube, on the prototype's precedent, because the part it
belonged to did not exist. It is now derived: half the tube to reach the groove's deepest
point, a machining web behind that, then half the pin. At 1-1/2 in that is **19 mm closer
in than the guess**, which shortens the frame link's reach and takes its bending moment
from 815 to 757 N·m.

That is the whole argument for declaring interfaces instead of inventing numbers. The
guess was not wildly wrong, and it was wrong.

### It is only as tall as the die, and that is a kinematic constraint

The followbar sits in the die's own z band and no taller, because the drive links occupy
the bands either side and **they sweep every radius**. Anything standing proud of the die
is in their path.

The pin that holds the followbar has the same problem and cannot be solved the same way —
it has to reach the frame links, which means crossing the drive links' band. So the
constraint is angular rather than axial: **the bend has to fit in the part of the circle
the followbar is not in.**

```
sweep:   315 deg free of the followbar, and the bend needs 185 deg
```

`bend_available_sweep()` takes the drive link's own angular half-width and the followbar's
at that radius out of the full circle, and `bend_mechanism_departures()` names it if the
bend will not fit. At 180 degrees there is 130 degrees to spare; the check exists because
nothing about it is obvious, and a 300 degree die would not fit.

### The clamp, and the plates that had to come first

The clamp holds the tube to the die while the die drags it round. Its mounting has a
topology problem, and it is worth setting out because the answer was not the clamp.

What has to be true at once:

1. It must sit **outboard of the tube** on the die's tail, where the die has no material —
   the tail's outer face *is* the tube's groove.
2. It must be **removable**. A closed channel in the tail would be simpler and stronger,
   and it was considered and rejected: you could then only load a tube by threading it in
   from an end, which makes multi-bend parts impossible. JD2's own worked example is a
   four-bend rollbar.
3. It cannot stand **above or below the die**, because the drive links are there. Note the
   reason carefully, because §17 gets it wrong in the other direction: the clamp is fixed
   to the die and **turns with it**, so it visits every angle in the arc and will meet a
   drive link at one of them. A part fixed to the *frame* does not move at all and can live
   in an angle the links never reach — which is exactly how the die lock is mounted.
4. The only die material it can reach is **inboard of the groove**, and the path is blocked
   — by the tube below the groove's flanks and by 3.2 mm of land above them.

Nothing about the die can satisfy all four. What can is a **plate on each face of the
die**, in the gap between the die and the drive links, whose tail **overhangs the tube**.
That overhang is the only material anywhere that the clamp can be pinned to. At 1-1/2 in
it reaches r = 169 mm, past the tube's outer surface at 133 mm.

So the clamp is a block like the followbar — capping the outboard half of the tube —
held by **two pins through the die plates**. Two rather than one, because one pin plus a
tube being dragged along its own axis is a hinge. Pulling the pins takes it off, which is
constraint 2. A bolt through the block presses the tube so it cannot slide: JD2 requires it
for wall under 0.065 in, and says to put a slice of larger tube between the bolt and the
work so it does not dimple [JD2-M32 p.7] — a consumable, not a part, and not modelled.

**The prototype got here first.** Its die assembly carries a plate above and below the die
halves, and its clamp has a 6.35 mm tongue running in a slot in those plates. This model
reached the plates from the constraints, and then found them already in the teardown.

### What the clamp load actually is

The tube is dragged round by the clamp, so the clamp carries the **tangential force in the
tube — the bending moment over the radius it is bent on**, `Mp / CLR`. At 1-1/2 in that is
8348 N. It is the same moment the drive pin sees, arriving at a different radius.

That force reaches the die through the plates, so the plate bolts carry it as a force plus
the moment it makes about the pivot — which is the full bending moment, because that is
what the clamp is holding. Standard bolt group: `F/n + M/(n r)`.

### The plates make the sliced die natural

A die with plates bolted to it is already a stack. Whatever the roadmap's laser-cut sliced
die turns out to be, it inherits the same bolt circle and the same interfaces, so that item
got cheaper by being blocked on this one.

## 16. Two dies behind one interface, and what the sliced one gives up

The forming die is the only part that needs a mill. `sliced_die.scad` is the same die made
from flat plates a laser or waterjet can cut — and it takes every dimension from the same
functions in `forming_die.scad`, so the arc, hub, tail, drive circle and groove root are
one expression used twice rather than two that agree until one moves. Nothing downstream
chooses between them; `die_style` does.

### No horizontal slicing can follow this groove

The groove is a half-round, and near its edges its surface runs almost parallel to the
die's axis — `dr/dz` goes to infinity at the part line. A stack always falls away from it
somewhere, and the further out it goes the worse it gets.

Each slice is cut to the groove's radius at **its own edge nearest the mid-plane**, so the
stack is everywhere at or inside the true groove and never proud of it. The tube gets line
contact on each rim. Cutting to each slice's mid-height instead would halve the gaps and
put every corner *into* the tube's path — the wrong trade for a surface being formed.

What that costs is **wrap**:

```
sliced die: 14 x 1/8 in slices, 3.18 mm each after facing
            supports 113 deg of the tube's section against 180 machined,
            and falls up to 10.53 mm away from the groove between rims
            wall factor here is 15.8 - a stepped groove suits thick wall and marks thin
```

113 degrees against 180. Thinner slices buy more — 1/16 in stock gets it to about 133 —
and no thickness reaches 180, because the last few degrees need a surface tangent to the
die's axis. That is not a defect in the implementation; it is what slicing a half-round
means, and the number is printed so the choice is made with it rather than around it.

### Who it is for

A stepped groove suits thick wall and marks thin, which is what **wall factor** measures,
so the report gives that alongside. The machined die remains the default. The sliced one
is there because a shop with a waterjet and no mill can build the whole machine, and
knowing exactly what that costs is better than not offering it.

### Not yet done

Each slice should come out as its own DXF. NopSCADlib names made parts through modules,
which does not fit a count that varies with the tube, so the stack currently exports as one
STL. That is a build-system problem rather than a modelling one.

## 17. The die lock, and the claim that was in the way

### What the cycle actually costs

```
cycle:   5 strokes of 1.22 m at the handle's end, re-pinning the drive pin between each
         5 drive holes index 180 deg of the 185 deg groove, so the last is over-pulled to
         41 deg and 1.39 m
handle:  1947 mm, needing 490 N of pull
```

Five pulls, each swinging the end of a two-metre handle through a metre and a quarter, and
between every one of them the drive pin comes out and goes into the next hole in the die.

**The stroke count is bounded by the holes, not by the pitch.** Each hole is used exactly
once, so `n` holes give `n` strokes and `n x pitch` degrees of die rotation — one pitch
more than the obvious guess, because engaging the last hole and pulling a pitch brings each
of the remaining `n - 1` round in turn and the final pull adds one more. Five holes at 36
degrees is 180, and a die with overbend wants 185, so **the last stroke is over-pulled**
rather than a sixth hole being drilled where there is no room. Both reference machines
carry five holes and must work the same way.

An earlier version of this file computed strokes as `ceil(arc / pitch)` with no reference
to how many holes existed, and reported six. At 1/2 in, where the die carries four holes
indexing 144 of the 185 degrees, it reported six against an actual four and said nothing
about the 41 degrees the last one has to make up.

### The real problem is springback between strokes

Stroke length is the lesser half of the case for a ratchet. **Nothing holds the die while
the drive pin is out**, so the tube springs back before it can be re-pinned and every
stroke gives back part of what the last one gained. JD2 solves that with two things: a die
lock pin, spring-loaded in a collar on the frame link, that "slides along the upper surface
of the forming die" until it drops into a drive hole and locks it; and an anti-springback
ratchet on the drive link's spacer tube [JD2-M32 p.7, p.8].

### The claim that said it could not be reached — withdrawn

This section previously said the lock pin could not be fitted without reordering the whole
stack, on this reasoning:

> *"To reach the die's drive holes from a frame link, the pin has to cross the drive links'
> band — and the drive links sweep every radius, so there is nothing at that radius they do
> not pass through."*

**That is withdrawn.** The drive links do sweep every radius, and it does not matter. What
a fixed part has to avoid is the band the links occupy in ANGLE, and that band is narrow,
because the machine indexes.

Work the cycle: the link engages the hole at world angle `psi`, pulls through the pitch,
the pin comes out, and the link swings **back** to `psi` — where the next hole has arrived,
because the die carried it there. Every stroke starts and ends at the same two angles. Over
a 180 degree bend the die turns 180 degrees and **the link never leaves a band one pitch
wide**. The frame stands still at a fixed angle, so a lock pin dropped from it meets the
drive link only if the two are angularly close.

The error was not arithmetic. It was describing a mechanism by the envelope of everything
it touches over a whole cycle, when what a collision needs is where two things are *at the
same time*. The sweep check in `bend.scad` carried the same mistake — it asked whether the
whole bend fitted between the followbar's keep-outs, which is the question for a machine
that does not index. It passed only because it was about five times too strict.

`bend_drive_band()` now states the band, and it is asked at a radius rather than answered
once: the same link is angularly narrow far out and angularly enormous close in. At 1/2 in
the link is 34.5 mm wide on a 23 mm drive circle, so its half-width there is 48 degrees and
the band is nearly four times the swing that generated it.

### Where it goes, and it is not two pitches

Two constraints looked like the whole problem, and one of them turned out to be a
distraction.

**Clearance.** The drive link's band must miss the pin by the link's half-width at the
pin's radius plus the pin's own. At 1-1/2 in that is 53 degrees.

**Phase.** A lock is only worth having if a hole is *at* the pin when the stroke ends. A
hole sits at angle `beta` exactly when `beta` is congruent to the stroke's home angle
modulo the pitch, and because the die advances by exactly one pitch per stroke, if that
holds once it holds every stroke.

From those two this section originally concluded that the pin sits on the frame link's own
axis, nudged by up to half a pitch to fix the phase, two pitches clear of the drive band.
**That is wrong, and the model is what said so.** Both constraints are satisfied and the
lock still does not work, because there is a third thing neither of them describes:

> **The die has to be there.**

The frame link points at the followbar, which is off the die's arc at the start of a bend.
The die's sector only rotates over that angle in the last 45 degrees. Phasing the holes to a
pin on the frame link's axis locks **the last two strokes of five and no others** — the
phase is right and the die is somewhere else.

More generally: the holes cover a window of only `(n-1) x pitch` in the die's own frame, and
the bend is longer than that window. So *where* the pin sits decides *which* strokes it
catches, and most angles catch some and miss others.

### One angle catches all of them

Holes sit at `a_i = inset + i x pitch` for `i` in `0 .. n-1`. Stroke `k` ends with the die
turned through `k x pitch`, so hole `n - k` is then at

```
a_(n-k) + k x pitch  =  inset + (n-k) x pitch + k x pitch  =  inset + n x pitch
```

The same angle for every `k` from 1 to `n`. **One pitch past the last drive hole**, and it
is exact rather than optimised — a hole arrives under the pin at the end of every stroke
without exception.

```
die lock: 7/8 in dia pin through the whole stack on r 73 mm at 198 deg - one pitch past the
          last drive hole, so a hole reaches it at the end of all 5 strokes
          on its own arm off the frame link, 57 mm wide for 477 N.m per link, drawn at the
          link's 87
          the drive band must clear it by 53 deg and stands 180 deg = 5 pitches off
```

At the die's start position that angle is just past the trailing edge of its arc, so the pin
begins a bend over air. Correct: a straight tube has nothing to spring back, and the die
rotates into the pin during the first stroke.

The clearance constraint survives as a check rather than a driver. The separation is
`n x pitch` by construction — 180 degrees at 1-1/2 in, against 53 needed — so it is checked
in both directions round the circle and never governs at any registered size.

### The frame link grows a second arm

198 degrees is nowhere near the followbar, so the frame link reaches it with an arm off the
same pivot. That is cheap — one more lobe on a plate already being cut — and the arm never
has to clear anything, because it lives in the frame links' own z bands, the same way the
followbar arm already runs straight over the die. **Only the pin crosses the drive links'
plane**, and only the pin needs the angular clearance.

The two arms carry unrelated loads and neither helps the other: the followbar arm reacts the
tube's push as a cantilever, the lock arm takes the springback moment back into the frame,
`Mp / 2` per link at the pivot. Both are drawn at the link's one width, which the followbar
sizes; the lock arm's own requirement is reported beside it and is under it at every size —
57 mm against 87 at 1-1/2 in, 84 against 106 at 2 in.

### It goes all the way through, and that is worth two pin sizes

Not a plunger hanging off the upper link. The angular exclusion holds at every radius, so
both drive links are clear and the pin can run the whole stack as a symmetric double-shear
joint like the frame pin.

That is not tidiness. Cantilevered off one frame link the span is from that link's
mid-plane to the die's, 39 mm at 1-1/2 in, and it wants **1-1/8 in**. Through the stack the
span is the standard `(t_centre + t_outer) / 2` and it wants **7/8**. A 1-1/8 in spring
plunger is not a plunger.

The drive pin and the lock pin go in the **same holes** at different angles, so they are one
size and the hole is sized once — on the lock's span, which is the longer of the two.

The cost is that the lock is inserted and pulled by hand like the drive pin, where JD2's
drops in by itself. A spring collar over the through pin would get that back; it is a
fitting rather than a load path and is not modelled.

### The exception

A die too small to carry drive holes is not indexed at all. JD2 drives those on the U-strap
pin instead [JD2-M32 p.7], the link really does swing the whole arc, and there is nothing to
lock into. **1/8 in and 1/4 in get no die lock.** That is what those sizes *are*, not a band
they fall outside, so it is reported as a plain fact and not as a departure.

## 18. What actually leaves the repo: cut files

Everything above decides what the machine *is*. This section is about what a shop is handed.

### The flat parts are cut, not printed

Seven of the fifteen made parts are a 2D outline in plate: the two frame links, the two
drive links, the two die plates, the base, and the pedestal foot. A laser, waterjet or
plasma table makes those from a **DXF**, and until now the model emitted them only as STL —
a mesh nobody can quote from.

They are now `dxf()` parts. `just build` writes `dxfs/*.dxf`, and the BOM files them under
**"CNC cut"** instead of under "Printed". What is left under "Printed" — the forming die,
the clamp, the followbar — are the three parts with real depth to cut, and those genuinely
want a solid model.

### The profile is the deliverable, and the picture is drawn from it

Each flat part's file now yields a `<part>_2D()` profile and nothing else; the extrusion
belongs to whoever places it. `routed_plate()` is what places one, and it does four things
at once: names the part on the BOM, declares the DXF, extrudes the profile for the assembly
view, and colours it.

The fourth thing is the one worth writing down. When NopSCADlib poses the assembly for the
manual's renders it **imports the exported DXF** in place of the module's children. So the
picture in `readme.md` is drawn from the cut file itself, not from a parallel description of
it. A cut file that does not match the assembly cannot sit there quietly; it changes the
picture.

### Two things the DXF does not carry

**Curves are polylines.** OpenSCAD writes a DXF at the current `$fn`, so every eye and every
bolt hole arrives as a 90-segment polyline rather than an arc. Cutter CAM reads it fine and
cuts it fine, and it is worth knowing before someone opens the file and wonders. Raise
`facets` before exporting production files if the finish matters.

**The sliced die is still not exported.** Its slice count varies with the tube — 14 at
1-1/2 in — and NopSCADlib names a made part through a module, one module per file. A count
that is a function of the configuration does not fit that, so the sliced die remains a
report and a preview only. It is the last part of the machine with no cut file, and it is
the one that needs the most of them.

## 19. The three welds

Three joints on this machine are welded, and until now they were a sentence. Every other
load path here is sized from a stress and an allowable; these carried **everything the
machine sheds into the world** on the strength of the word "welded".

| joint | what it carries |
|---|---|
| lower frame link → base plate | the drive torque about the pivot, the operator's pull, and the overturning that pull makes at the working plane |
| post → base plate (top) | the drive torque, and the pull as direct shear. No bending: the load is applied at this end, so its lever arm has not started |
| post → foot plate (bottom) | the drive torque, and the pull over the **whole** working height |

### Weld as a line

A fillet's strength goes with its **length**, so a weld group is treated as a line of unit
width rather than as an area. Its "area" is a length in mm and its second moments come out
in mm³ — one power down from their solid-section namesakes. Divide a moment by one of those
and you get **newtons per millimetre of weld**, with no leg size anywhere in the arithmetic.

That is the whole reason for doing it this way. The required leg falls out at the end, by
dividing by what one millimetre of fillet can carry, instead of being guessed, checked, and
guessed again.

The base joint is two parallel runs along the frame link's followbar arm; both post joints
are a ring round the post's OD. In-plane torsion and direct shear are added as scalars —
they are collinear at one point of the group and smaller everywhere else, which is the
standard hand check. Bending is combined as a vector, because it pulls the throat open
rather than shearing it.

### The allowable, and how good it is

**0.30 × the electrode's nominal tensile strength, on the effective throat** — 21 ksi /
144.8 MPa for E70XX [AISC-WELD]. The throat is `leg / √2`, the shortest path across the
corner, which is where a fillet loaded any way at all actually fails.

**This is the weakest-sourced number in the project, and it should be said plainly.** Every
other allowable here comes from a peer-reviewed journal or a mill data sheet; this one comes
from two secondary pages that restate AISC and AWS rather than being them. The figure itself
is not in doubt — it is the most-quoted number in weld design and the two sources agree to
three digits — but the provenance is one step further out than anything else in the load
path.

### The code minimum is not about strength, and it governs

AISC also sets a **minimum** leg from the thickness of the parts joined [AISC-360 Table
J2.4], and it has nothing to do with the load. It is a heat-input rule: too small a bead
against heavy plate chills too fast and cracks.

**The base weld is minimum-governed at every size in the range** — a 1/8 in fillet, both
sides of the link, where the load asks for well under a tenth of that. At 1-1/2 in it
carries 52 N/mm against 325 N/mm of capacity. The joint that looked like the biggest open
question turns out to have a factor of six in hand, and that is worth knowing rather than
assuming either way.

The post welds are the opposite: **load-governed at every size but the smallest**, and one
of them runs at 97 % of a 1/8 in fillet before stepping to 3/16. The report prints both
figures side by side and says which decided it, because a minimum-governed joint has margin
and a load-governed one does not.

### Which part the table is read against — a live disagreement

Table J2.4 is read against the **thinner** part joined. That is current AISC and current
AWS. Older editions read it against the **thicker** part, and secondary sources still repeat
that, so both readings are in circulation and **they do not agree here**: 1/4 in link on
3/8 in plate gives 1/8 in one way and 3/16 in the other.

Thinner is taken, and not because it is smaller. The rule exists so that a bead is not
chilled by the mass around it. On the pedestal's 0.120 in post wall the **larger** figure is
the dangerous one — it burns through the very part the rule is there to protect. The code
carries that logic itself: where the table minimum exceeds the thinner part's thickness, the
minimum is limited to that thickness, which is why two of the post welds come out at 3.05 mm
— the wall — rather than at a round 1/16 in step.

### A check I got wrong, and what it taught

A weld cannot be stronger than the metal it is welded to, so the first version asserted the
resultant against `0.4 Fy × t` of the part underneath. **It fired on seven perfectly good
sizes.**

The reason is worth keeping. At the post's foot, 300 of the 315 N/mm is **bending** — a
normal force pulling on the fusion face, not a shear across it — and comparing it to a
*shear* allowable conflates two limit states. The real check on that force is the post's own
section, which `pedestal_report()` already makes and which passes with room (71 MPa
equivalent against 100 allowable). The base weld is the opposite case, all but 4 % of it
in-plane, and there the same check is the right one and is kept.

The lesson is not "the check was too conservative". It was checking the wrong thing, and
only looked conservative.

## 20. What you actually order: stock lengths

Two things stood between the parts list and someone using it, and both were invisible until
somebody tried to read the list as a list.

### A stack thickness is not a length you can buy

The model computes what a fastener has to cross and, until now, billed that number. So the
list asked for a `1/2 in × 1.556 in` bolt and a `1-1/8 in × 3.565 in` pin. Nobody stocks
those.

**Pins are ordered by USABLE length** — head underside to the cotter hole — and that comes in
**quarter-inch steps**, because a clevis pin's holes are spaced a quarter inch apart and
which one takes the cotter is what sets the length [MCMASTER-CLEVIS]. So the stack is the
**grip**, and `pin_usable_length()` rounds it up. `layout_pin_length()` became
`layout_pin_grip()` and lost the 6 mm allowance it used to add for a cotter: usable length
already ends at the cotter hole, so the allowance was the same thing counted twice.

**Bolts round the same way**, to a quarter inch. That step is *reasoned* rather than
catalogued — it is where the common lengths fall through the range this machine needs, and
no source was obtained for it.

### The rounding leaves slack, and the slack is a part

A stack never lands exactly on a step, so the ordered pin is always a little long — up to a
quarter inch. That gap is **washers**, and a builder who is not told about it assembles a
joint that rattles and blames the clearances. At 1-1/2 in the frame pin grips 84.55 mm and
orders 88.9, so 4.35 mm of washers go under its head. The report says so.

### What holds a pin in — see §22

The holes were being drilled with nothing to go in them, so retainers were added: a cotter
for pins fitted once, a clip for pins pulled every stroke. **That was wrong, and §22 records
why and what replaced it.** The reference machine has no retainer of any kind on any pin.

Worth knowing while doing the shopping: **ASME B18.8.1 stops at 1 in** [ASME-B18.8.1], and
two of the pins here — the 1-1/8 in frame pin at the top of the range, and the 1-3/8 and
1-1/2 in rows the series was extended to — are larger than the clevis pin standard covers.

## 21. The build, in four stages

The manual had one picture of a finished machine and a flat list of parts. That is a
drawing, not instructions. It is now four stages, and each one is a thing somebody actually
does at a bench rather than a way of grouping the model:

1. **The base weldment** — the lower frame link welded flat to the base plate, plus the post
   and its foot on a pedestal build. §19 sizes those welds; the instructions say to tack both
   ends and check flatness before running, because distortion is the risk here rather than
   strength.
2. **The die** — the two die plates bolted to the faces of the forming die, never to come off
   again. Bolt one on, spot the other from it, and check the tails are parallel before
   tightening: those tails are the only thing the clamp pins to, so a twist here is a clamp
   that will not go on.
3. **The handle** — the two drive links joined by the spacer bolts and their tubes. Joined at
   the grip end only, because the pivot end has to stay open for stage 4.
4. **The machine** — the die assembly slides into the handle fork from the pivot end, the
   frame pin drops through, and the anchor bolts go in last.

Stage 3 into stage 4 is the one worth stating outright: the handle is a **fork**, joined only
at its far end, so the die goes in sideways rather than being lowered in. Build it the other
way round and it does not go together.

### Building the stages is what found eighteen missing parts

This was the real return on the work, and it was not the intended one.

A fastener is billed by being **placed**. Drilling a hole for one bills nothing. So the
model had, for a long time, holes with nothing in them and a parts list that did not mention
it: **six** bolts holding the die plates to the die, the clamp's own bolt, **four** pedestal
foot bolts, and **seven** pin retainers (§20). Eighteen items, every one of them load-bearing
or the machine does not work, and none of them on the list.

Nothing catches this except assembling the thing. A gate can check that every reported value
is a number; it cannot know that a hole is lonely. Laying the build out as stages is what
made each fastener's absence visible, because a stage with no fasteners in it reads as
obviously wrong in a way a flat list does not.

### Two headings that are the library's words

`readme.md` files the forming die, the clamp and the followbar under **"3D printed parts"**.
They are machined. That is NopSCADlib's word for a part you make rather than buy, and it is
not worth forking a library over — the flat parts now sit under **"CNC routed"**, which is
right, and the file header says plainly what the other heading means.

## 22. Where the pin heads go, and what the manual settled

Building the assembly views surfaced a defect that had been in the model since the base
existed: **the frame pin and the followbar pin had their heads inside the base plate.** Both
were placed at the lower frame link's underside, head down. That link is welded flat to the
base plate, so the head occupied −48.9 to −42.3 mm and the plate occupied −51.8 to −42.3.
The head was entirely buried in it, and the plate has no holes but the four anchor bolts.

It was invisible because the 1-1/8 in pin row has no head geometry looked up, so nothing was
drawn. The one row that *has* been measured — the 3/4 in followbar pin, off the prototype's
CAD — draws its head, and its head was inside the plate.

### Three candidate answers, and none of them was right

The options looked like: a headless pin bottoming on the plate; a through-bolt with a nut
underneath; or clearance holes so the heads recess. The argument for the second is a good
one and it is the right instinct — **proven design over bespoke** — because a bolt-and-nut
pivot is a thing the world has built a million of, and a headless turned pin is a thing you
would have to make.

So the question was settled the only way it should have been: by reading what the machine
this one is modelled on actually does. The Model 32 manual is a source this project already
cites and had, until now, only mined for tooling practice.

### What JD2 does

Its frame pins are **plain, loose, drop-in pins**, and there are **two** of them — the same
part serves the die pivot and the followbar. They are not bolted, not headed in the
instructions, and not retained:

> **D)** Insert the 1 1/4" Frame Pins in the holes shown above. Now, tighten the 3/4" nuts as
> tightly as possible, while insuring the two pins are perfectly vertical and slide easily
> through their respective holes. — [JD2-M32 p.1]

That single step kills the bolt option outright, and for a reason neither candidate argument
had reached: **the pins are the alignment gauge.** The frame bolts go in hand tight, the pins
go in, and the nuts are torqued while you check the pins still slide. A pivot with a nut on
the bottom cannot do that — and cannot be pulled at all once the machine is bolted to a
bench, which you have to do to change a die ("Place the forming die into the bender using the
1 1/4" frame pin", p.7) and to install the drive links (p.1).

### And there are no retainers anywhere

Searched end to end, the manual contains **no cotter, no clip, no snap ring, no retainer of
any kind, on any pin**. The word does not appear. There is one instruction covering all of
them:

> Make sure all pins are completely seated in their holes. Failure to do this may cause
> damage to the bender links or worse yet the operator may slip and fall. — [JD2-M32 p.7]

That overrules §20's retainers, which were **an invention** — reasonable-looking, internally
consistent, and not what anybody builds. Two facts make plain pins correct here and both are
properties of this machine rather than of that one:

- **Every hole is vertical.** The die turns about a vertical axis, so a pin that is upright
  at the start of a bend is upright at the end. Nothing is ever inverted.
- **Every pin comes out.** The frame pin to change a die, the drive pin at every stroke, the
  lock pin by hand to release the die. A cotter is a thing that stops you doing that.

### What was built

**Every pin goes in head up.** That is the smallest change that fixes the defect, and it is
better than the headless option on its own terms: the head is on top where there is room, it
holds down the plate above it, it is the handle you pull the pin out by — and it keeps the
part a catalogue clevis pin, so the project's one real order number survives. The headless
idea would have thrown `98306A868` away and replaced it with a turned part.

What is under a pin is recorded, because the two cases are not equally forgiving. The frame,
followbar and lock pins sit over the base plate and land on it. The drive, U-strap and
spacer pins hang in the stack, and there the **head is the only thing holding the pin up** —
so a registry row with no head dimensions is a live gap, and the report names it as one:
`TO ORDER: the drive pin hangs in the stack on a head this registry has no dimensions for`.

### One thing this opens, and does not close

§14 deleted the frame bolts, on the argument that the frame pair "is already joined at both
ends — by the frame pin at the pivot, the followbar pin at the far end". With plain drop-in
pins that is **located, not joined**: the upper frame link is now held down by two pin heads
resting on it and nothing else.

JD2 has both — loose pins *and* 3/4 in bolts through 1 in OD spacer tubes clamping the frame
pair. Their frame bolts do not react the drive torque; they clamp the pair and set its
spacing, and §14 sized them for the wrong job before deleting them. Whether to put them back
is a separate decision and is not made here.

## 23. The frame ties, and a bullet that was wrong

§14 deleted the frame bolts and gave three reasons. Two of them were right. The middle one —
that the pair "is already joined at both ends, by the frame pin at the pivot, the followbar
pin at the far end" — assumed those pins **join** the frame. §22 established that they are
plain, loose, drop-in pins. They *locate* the pair. Nothing joined it.

So until now the upper frame link was a 6 kg plate resting on three pin heads, and pulling
the frame pin to change a die took it off with them.

### The job the frame bolts actually do

§14 sized them to react the drive torque out through the mounting surface, found the span
impossible at both ends of the range, and deleted them. **That was the wrong job.** On the
reference machine the frame bolts do not react the drive torque either — they clamp the two
frame links to a fixed spacing through a length of tube, and they happen to continue on
through the base to nuts underneath, which is what anchors the machine. One set of fasteners,
two jobs, and §14 only analysed the second.

This machine keeps the two jobs apart: four anchor bolts at the base plate's corners react
the torque (that reasoning still stands, and the arm is better), and two frame ties hold the
frame together. What makes a tie a *bolt through a tube* rather than just a bolt is that the
tube sets the gap — so a tie can be pulled up hard without pinching the die and the drive
links between the frame plates.

### The load nobody had derived: the handle's own weight

**THE LINK IS THE HANDLE** (§14). There is no separate lever to pick up and put down, so two
metres and nine kilos of drive link hang off this machine permanently, and that weight has to
go somewhere. Nothing in the model carried it.

Where it goes: the pair sags, and a sagging cantilever pivots about whatever it last touches —
the die plate's outer edge, which the upper drive link lies on. Everything inboard of that
edge goes **up**, including the drive link's own tail behind the pivot, which then bears on
the upper frame link. Nothing else is above it.

```
lift = W (r_centroid - r_bearing) / (r_bearing + w/2)
```

with the centroid integrated over the same taper the mass is. It scales alarmingly, because
both the handle's length and its mass grow with the tube:

| tube | handle | pair | lift |
|---|---|---|---|
| 1/2 in | 151 mm | 0.5 kg | **0 N** — the handle does not reach past the die |
| 1 in | 590 mm | 2.7 kg | 22 N |
| 1-1/2 in | 1947 mm | 9.0 kg | **336 N** |
| 2 in | 4403 mm | 26.4 kg | **2129 N** |

Two kilonewtons trying to lift the top plate off, at the top of the range, from nothing but
gravity. That is a real load and it is a direct consequence of the integral handle — a machine
with a lift-off lever, which is what both reference machines have, does not have it at all
while the lever is off the bench.

### Where they can go: a window, not a guess

Everything between the frame links either turns or sits there, and all of it starts at the
front of the machine, so it merges into **one blocked band containing zero**:

- the **die plate's tail**, which reaches half again as far as the CLR and carries that reach
  through the die's whole rotation;
- the **drive links**, over their swing plus their own half-width at the radius asked about;
- the **followbar**, which does not move but is a big block — and at 1-1/2 in it spans −55° to
  −27° where the tail only reaches −43°, so it is the followbar that sets the limit, not
  anything that moves.

What is left is the arc behind the die, and it is 125° to 190° wide across the whole range —
much more room than it sounds like there should be. The ties go in it, symmetrically about its
middle and as far apart as it allows, each keeping its own half-width plus a web off the
boundary so that a tie is never the thing a passing tail has to miss by a hair.

**One tie where two will not fit apart.** On the two sizes with no drive holes the link swings
the whole arc instead of one pitch, the window collapses to 40–57°, and pushing a pair as far
apart as that allows puts them **0.65 mm** from each other — which is not two fastenings, it
is one slot. A single tie still holds the plate down, which is the job. What it gives up is
resisting rotation about itself, and the frame pin bearing in its hole does that at every
size anyway.

### The base plate had to follow

The plate is what the lower frame link is **welded to**, and the link had just grown two arms.
Its size was still a rectangle drawn round the followbar arm from when that was the only arm
there was — so one tie landed on it and the other hung over the edge, where a nut has the
thickness of the base plate to fit in.

It is now cut to the link's own bounding box plus a margin, in the link's own frame, which is
the world's — so it is drawn where it goes and nothing rotates it any more. At 1-1/2 in it
goes from 283 × 174 to 417 × 259 mm.

**The anchor bolts got smaller, which is the right surprise.** Four bolts on a bigger
rectangle sit on a 225 mm radius instead of 137, so the shear in each nearly halved and the
selection dropped from 1/2 in to 5/16. A bigger plate and smaller bolts is what sizing the
plate honestly does.

### What the ties are sized on, and what actually decides it

The lift, shared equally between them — conservative, because the pins take some of it and
are not counted on for any. It never governs: even 2129 N shared two ways asks for a **3 mm**
bolt. So the size comes from a floor, and the floor is the drive links' own spacer bolt — the
same job, in the same plate, on the same machine. A frame tie smaller than the handle's own
spacer would be an odd thing to build.

The reference machine uses 3/4 in here and this uses 5/16. That is not a disagreement: theirs
are also the anchor bolts.

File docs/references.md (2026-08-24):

# References

Every external source this design rests on, what it is used for, and where in the repo
that use lives. Kept so a number in the CAD can be traced back to the thing that
justifies it.

**Verification status is recorded per source.**

- **read** — the full text was retrieved and the cited passage confirmed
- **abstract** — only the abstract or a catalogue summary was available
- **unread** — cited from a secondary source, not obtained

Grades: **[PR]** peer-reviewed · **[STD]** standard or government handbook ·
**[TX]** textbook / reference · **[TP]** trade press · **[VN]** vendor documentation.

Vendor catalogue pages and McMaster part numbers that justify a single registry row are
cited inline on that row, not here. This file carries the sources that shape the design.

---

## Machine architecture and tooling practice

**J D Squared Inc. (2009).** *Model 32 Tube Bender — Assembly & Operating Instructions.*
<https://support.jd2.com/MiscDown/dl/M32BDirections.pdf> **[VN]** · **read**
Cited as **[JD2-M32]**. The closest published description of the machine being rebuilt
here. Supplies: the trade vocabulary (forming die, U-strap, followbar, drive link, frame
link, drive holes); tube-versus-pipe specification and the die-must-match-the-tube rule
(p.4); **the forming die groove is profiled so the tube does not fully seat** (p.4); the
followbar's angled rear insert and its deliberate ride height below the die groove (p.5);
**drive holes drilled 1/8 in oversize on a 7/8 in pin, on purpose** (p.7); dies under 3 in
CLR carry no drive holes (p.4, p.7); pin sizes 1-1/4 in frame, 7/8 in drive and U-strap;
the 36 in handle and the 1-3/4 x .095 mild steel claim (p.2); hydraulic pressures for a
10-ton cylinder on three test materials (p.3); springback of 3–4 degrees on 1-1/2 x .120
mild steel and roughly double for chromoly (p.9, p.11); never lubricate a round-tube
forming die groove (p.7).
**Re-read for the frame assembly (p.1, p.7), and it settled a design question.** The frame
pins are plain, loose, drop-in pins - two of them, the same part serving the die pivot and
the followbar - and the assembly procedure makes them the ALIGNMENT GAUGE: frame bolts hand
tight, pins in, then "tighten the 3/4 nuts as tightly as possible, while insuring the two
pins are perfectly vertical and slide easily through their respective holes". Searched end
to end the manual has **no cotter, clip, snap ring or retainer of any kind on any pin**; the
word does not appear. One instruction covers all of them: "make sure all pins are completely
seated in their holes... failure to do this may cause damage to the bender links or worse yet
the operator may slip and fall". Also: the frame pair is clamped by 3/4 in bolts through 1 in
OD spacer tubes, which continue through the base and the mounting surface to nuts underneath,
so one set of bolts clamps the pair AND anchors the machine; and the die locking pin carries
a 3/16 x 1-1/4 roll pin so it can be parked by lifting and rotating it (p.8).
→ `docs/design-basis.md` §1, §2, §5, §7, §22; `scad/purchased/pin.scad`

**Pro-Tools (n.d.).** *Tube and Pipe Bender, 105 Series Heavy Duty — specifications.*
<https://pro-tools.com/products/manual-tube-and-pipe-bender-105-series-heavy-duty> **[VN]** · **read**
Cited as **[PROTOOLS-105]**. Capacity 1/2 to 2 in OD round tube to 0.134 in wall; minimum
CLR approximately 3 x OD; maximum CLR 7 in; 5/8 in thick frame arms; bends to 180 degrees
depending on the die. One of the two machines that fix the upper size bound.
→ `docs/design-basis.md` §3, §4

**Pro-Tools (n.d.).** *90 Degree Round Tube Dies for 105 Brute Tube and Pipe Bender.*
<https://pro-tools.com/pages/90-degree-round-tube-dies-for-105-brute-tube-and-pipe-bender> **[VN]** · **read**
Cited as **[PROTOOLS-DIES]**. The full OD x CLR matrix actually sold, 3/4 in through
2-1/2 in OD. Every entry falls between 2.8D and 4.8D. This is the catalogue the CLR
registry is built from and the empirical check on the 3D rule.
→ `docs/design-basis.md` §4

**Swagelok (rev. 5).** *Hand Tube Bender Manual, MS-13-43.*
<https://www.swagelok.com/downloads/webcatalogs/en/ms-13-43.pdf> **[VN]** · **abstract**
Cited as **[SWAGELOK-MS-13-43]**. Bend radii for the small end: 0.56 in on 1/8 in tube,
0.56 and 0.75 in on 1/4 in, 0.94 in on 5/16 and 3/8 in, 1.50 in on 1/2 in — i.e. 2.25D to
4.5D. Fixes the lower size bound at 1/8 in. Values taken from the catalogue's ordering
table as surfaced in search; the PDF itself was not opened, so this is **abstract** and
should be upgraded before any of these radii drive geometry.
→ `docs/design-basis.md` §3, §4

## Bend geometry and bendability

**Bend Tooling Inc. (n.d.).** *Tube Bending Calculations & Formulas.*
<https://bendtooling.com/tube-bending-formulas/> **[VN]** · **read**
Cited as **[BENDTOOLING]**. The authoritative statement of the two ratios, in the correct
direction: wall factor `Fw = T / W` (OD over wall) and D of bend `Fd = R / T` (CLR over
OD). Also clamp length, pressure die length `Lp = (R x pi x (B/180)) + (T x Kr)`, arc
elongation, and a bend difficulty rating. Explicitly states that **no effective formula
for springback exists** — it is machine- and material-specific.
→ `docs/design-basis.md` §4

**Pro-Tools (n.d.).** *Wall Factor and D of Bend: Getting to the Center of the Centerline
Radius Debate.*
<https://pro-tools.com/blogs/protoolsusa/42288387-wall-factor-and-d-of-bend-getting-to-the-center-of-the-centerline-radius-debate> **[TP]** · **read**
Cited as **[PROTOOLS-WALLFACTOR]**. The 3 x OD rule of thumb for the minimum centreline
radius achievable without an internal mandrel, and its own caveat that the rule is "very
rudimentary" and material-specific.
→ `docs/design-basis.md` §4

**The Fabricator (n.d.).** *4 essential modes of tube bending.*
<https://www.thefabricator.com/thefabricator/article/tubepipefabrication/4-essential-modes-of-tube-bending> **[TP]** · **abstract**
Cited as **[THEFABRICATOR-4MODES]**. Tightest achievable CLR is 1 x diameter; 1.5 x
recommended where possible; 3 x OD for benders without a mandrel; outside wall thins up to
33 %. **Caution:** the summary read of this article states wall factor as *wall over OD*,
which is inverted relative to [BENDTOOLING]. The inverted form was not adopted; the
discrepancy is the reason §4 states the direction explicitly.
→ `docs/design-basis.md` §4

**Rogue Fabrication (n.d.).** *Mandrel Bending: What It Is and When You Need It.*
<https://www.roguefab.com/mandrel-bending/> **[TP]** · **abstract**
Cited as **[ROGUEFAB-MANDREL]**. 3.0D as the threshold below which a mandrel is worth
serious consideration; below 2.0D generally required; unsupported tube tighter than 2 x OD
develops excessive ovality. Thin wall, at or below 18 ga, needs more support.
→ `docs/design-basis.md` §4

**Tang, N.C. (2000).** "Plastic-deformation analysis in tube bending." *International
Journal of Pressure Vessels and Piping* 77(12):751-759.
[doi:10.1016/S0308-0161(00)00061-2](https://doi.org/10.1016/S0308-0161(00)00061-2)
**[PR]** · **unread**
The standard analytical treatment: stress in bends, wall thickness change, neutral axis
deviation, bending moment and flattening. **Paywalled and not obtained** — recorded here
because it is the source that would replace the plain plastic-moment floor used in §6 with
a real bending-moment model. Nothing in the current design rests on it.
→ roadmap for `docs/design-basis.md` §6

**Bend Tooling Inc. (n.d.).** *Encyclopedia: clamp die.*
<https://bendtooling.com/encyclopedia/clamp-die/> **[VN]** · **read**
Cited as **[BENDTOOLING-CLAMP]**. Clamp die length `L = t x k - r`, t the tube diameter,
k a rigidity constant, r the centreline radius; and the minimum: "A minimum value for L,
if the clamp die cavity is smooth, is around two times the tube diameter." Serrations and
knurling permit L to be about half a smooth cavity's. This is what the die's tail length
is cut from.
→ `docs/design-basis.md` §12, `scad/utils/bend.scad`

**Benderparts (n.d.).** *Tube Bending Formulas — Rotary-Draw Precision Calculations.*
<https://www.benderparts.com/tube-bending-formulas/> **[VN]** · **read**
Cited as **[BENDERPARTS-FORMULAS]**. Confirms `Fw = T / W` and `Fd = R / T` in the same
direction as [BENDTOOLING], gives the rigidity constant a default of 2 — which is where
`k = 5` comes from — and states smooth clamps start around 2 x OD of engagement and
serrated around 1 x. Carries no clamp-length formula and no groove-depth rule, which is
itself useful: two vendors' formula sheets and neither specifies the groove.
→ `docs/design-basis.md` §12, `scad/utils/bend.scad`

**Tools For Bending (n.d.).** *Tooling Design.*
<https://www.toolsforbending.com/tooling/tooling-design/> **[VN]** · **read**
Bend die and clamp die "hardened tool steel or alloy steel, heat treated and nitrided";
pressure die "alloy steel and nitrided". **Cited here as a correction.** A claim about the
part line and groove depth was attributed to this page from a search summary and used in
`forming_die.scad`; the page was then fetched and does not contain it. The claim is
withdrawn. Nothing in the model rests on this source except the material note.
→ `docs/design-basis.md` §5

**The Fabricator (n.d.).** *Getting a grip.*
<https://www.thefabricator.com/tubepipejournal/article/bending/getting-a-grip> **[TP]** · **unread**
Cited as **[FABRICATOR-GRIP]**, and cited only to record that it could NOT be read: the
site returns 403. A summary of it supplied the "grip length at least 3 x OD" rule and the
"3 x OD at 1 D falling to 1 x OD at 5 D" scaling, and the 3 was used in the model until
the two sources above were read and both said 2. The scaling may well be right; it is not
in the model because nobody here has seen it stated.
→ nothing; recorded so the next person does not re-import it from a summary

## Material properties

**Totten Tubes (n.d.).** *ASTM A513 Specification Information — Hardness Limits and Tensile
Properties for A513 Steel Round Tubing.*
<https://www.tottentubes.com/astm-a513-specification-information> **[VN]** · **read**
Cited as **[TOTTEN-A513]**. Yield bands across grades 1008–1026 by processing condition:
as-welded 30–45 ksi, normalized 23–40 ksi, sink-drawn 38–55 ksi, mandrel-drawn 50–70 ksi,
mandrel-drawn stress-relieved 45–65 ksi. Registered as **bands**, because that is what the
source gives; picking a midpoint would invent a precision the specification does not have.
→ `docs/design-basis.md` §6

## Mechanics

**Plastic moment / plastic section modulus.** Standard plasticity result; the hollow round
section's plastic modulus is `Zp = (D^3 - d^3)/6`.
<https://en.wikipedia.org/wiki/Plastic_moment> **[TX]** · **read**
Cited as **[PLASTIC-MOMENT]**. Used as a **lower bound** on the drive torque: it ignores
strain hardening, followbar and U-strap friction, and the travelling hinge, all of which
raise the real figure.
→ `docs/design-basis.md` §6

## Structural allowables and materials

**Goel, S.C. (n.d.).** "Combined Shear and Tension Stresses." *AISC Engineering Journal.*
<https://ej.aisc.org/index.php/engj/article/download/467/466/466> **[PR]** · **read**
Cited as **[AISC-GOEL]**. States the AISC allowable stress design fractions directly:
"tension, Ft = 0.6Fy, and that in shear, Fv = 0.4Fy", against the von Mises shear yield of
about 0.6Fy. Every pin diameter and both link widths are cut from these two numbers.
**Read properly, and worth it:** a search summary of the same topic conflated the ASD
allowable (0.4Fy) with the von Mises shear yield (0.6Fy), which are a factor of 1.5 apart.
→ `scad/utils/pin_sizing.scad`, `docs/design-basis.md` §13

**McMaster-Carr (n.d.).** *Selectable-Length Clevis Pins.*
<https://www.mcmaster.com/products/clevis-pins/performance~selectable-length/> **[VN]** · **abstract**
Cited as **[MCMASTER-CLEVIS]**. The one fact taken: a clevis pin's cotter holes are
**spaced 1/4 in apart**, and which one the cotter goes through is what sets the usable
length. That is the increment `pin_usable_length()` rounds to. **Abstract:** the statement
comes from the product listing as surfaced in search, not from a page that was opened, and
it describes the selectable-length line specifically — a plain clevis pin has one hole and
the same 1/4 in step is then a statement about which lengths are stocked rather than about
holes in one pin.
→ `scad/purchased/pin.scad`

**ASME B18.8.1, Clevis Pins and Cotter Pins (Inch Series).** Cotter pin nominal sizes run
1/32 in to 3/4 in with a tabulated gage hole for each; 1/8 in pin to a 0.141 in hole.
<https://amesweb.info/Fasteners/Pins/Cotter-Pin-Sizes-Chart.aspx> **[STD]** · **abstract**
Cited as **[ASME-B18.8.1]**. Reached through a secondary table, not obtained. Recorded
because it is the standard that WOULD settle the cotter sizes this model deliberately leaves
open, and because it also settles that the clevis pin standard stops at 1 in — two of the
pins here are larger than anything it covers.
→ `scad/purchased/pins.scad`

**MechSimulator (n.d.).** *Fillet Weld Strength Design — Throat, Allowable Stress & FOS.*
<https://mechsimulator.com/blog/articles/weld-strength-fillet-weld-design-guide/> **[TP]** · **read**
Cited as **[AISC-WELD]**. States the allowable directly: the shear allowable on a fillet
weld's effective throat is **0.30 x the electrode's nominal tensile strength**, which for
E70XX is 21 ksi / 144.9 MPa, and the throat is `0.707 x leg`. Corroborated independently by
a second calculator page reached from a different search. **Secondary, and marked as such:**
both restate AISC/AWS rather than being it, and the specification itself was not obtained.
The number is not in doubt — it is the most-quoted figure in weld design — but the
provenance is one step removed from every other allowable in this project.
→ `scad/utils/weld.scad`, `docs/design-basis.md` §19

**IDEA StatiCa (n.d.).** *Detailing of bolts and welds according to AISC.*
<https://www.ideastatica.com/support-center/detailing-of-bolts-and-welds-according-to-aisc> **[VN]** · **read**
Cited as **[AISC-360]** for the two detailing rules the weld sizing uses. Minimum fillet
size, Table J2.4, read against **the thickness of the thinner plate**: 1/8 in to 1/4 in,
3/16 in to 1/2 in, 1/4 in to 3/4 in, 5/16 in above. Maximum size along an edge, J2.2b,
quoted verbatim: "For plate thickness smaller than 1/4 in, the weld size should be no bigger
than plate thickness. For plate thickness equal to or higher than 1/4 in, the weld size
should be no bigger than the plate thickness -1/16 in."

**A disagreement worth recording.** A second secondary source states the minimum is read
against the **thicker** part, and on this machine the two readings differ — 1/4 in link on
3/8 in plate gives 1/8 in one way and 3/16 in the other. Thinner is current AISC and current
AWS, and the commentary rationale quoted for the change ("the prevalence of the use of
filler metal considered to be low hydrogen") is consistent with that direction. Older
editions read it against the thicker part, which is why the wrong figure is still in
circulation.
→ `scad/utils/weld.scad`, `docs/design-basis.md` §19

**Elgin / MW Components (n.d.).** *Carbon Steel Grade 1018 Data Sheet — AISI 1018, cold drawn.*
<https://www.mwcomponents.com/uploads/Resource-Center/Elgin-Material-Sheets/Carbon-Steel-Grade-1018-Data-Sheet_Elgin.pdf> **[VN]** · **read**
Cited as **[MW-1018]**. Cold drawn 1018: tensile ultimate 440 MPa, **yield 370 MPa**. The
pin material anchor. Note what it does NOT settle: the prototype's pin is sold as
"1004-1045 carbon steel", a range rather than a grade, and 1004 sits below this. A pin has
to be ordered to a stated grade or the margin re-checked.
→ `scad/purchased/pins.scad`

**ASTM A36 structural steel.** Specified minimum yield 36 ksi (250 MPa), tensile
400-550 MPa. <https://www.ssab.com/en-us/brands-and-products/commercial-steel/structural-steel/astm-a36> **[STD]** · **abstract**
Cited as **[ASTM-A36]**. The yield is definitional — the grade is named for it — and
several vendor pages agree, but the standard itself was not obtained. It is a MINIMUM: a
real plate is stronger, and nothing here is sized on the difference.
→ `scad/purchased/plates.scad`, both links

## Human factors

**Federal Aviation Administration (2003, amended Oct 2009).** *Human Factors Design
Standard (HFDS), Chapter 14: Anthropometry and biomechanics.*
<https://hf.tc.faa.gov/hfds/download-hfds/hfds_pdfs/Ch14_Anthropometry_and_biomechanics_Oct2009.pdf>
**[STD]** · **read**
Cited as **[HFDS-2009]**. Exhibit 14.5.3.1 (from MIL-HDBK-759B, 1992), horizontal push or
pull a designer may require: 110 N low traction, 200 N medium traction, 240 N one hand
braced, 310 N high traction, **490 N both hands braced against a wall or feet anchored on
non-slip ground**, 730 N with the back. Exhibit 14.5.2.1, 5th-percentile male arm strength
for control forces: pull 177.6–199.2 N depending on elbow flexion. 490 N is the ceiling the
handle length is derived against.
→ `docs/design-basis.md` §6

**ISO 11228-2:2007.** *Ergonomics — Manual handling — Part 2: Pushing and pulling.*
<https://www.iso.org/standard/26521.html> **[STD]** · **unread**
Recorded, not used. It is the obvious companion to [HFDS-2009], but it is restricted to
two-handed whole-body exertions while standing or walking and is paywalled. If the handle
force budget is ever contested, this is the standard to buy.

---

## On `references.bib`

There is no BibTeX file yet, on purpose. Exactly one source above is literature
(Tang 2000) and it is unread; the rest are vendor documentation and government
handbooks, which by the same convention are cited inline rather than exported. A `.bib`
holding one entry is ceremony. It gets written when the literature side of this list is
worth importing in one go.

## Software

**Palmer, C. (2018–).** *NopSCADlib.* <https://github.com/nophead/NopSCADlib> **[VN]** · **read**
The library this project is built on, used for its full BOM and assembly machinery, not
just its vitamins: `assembly()` build steps, `stl()`/`dxf()` for made parts, `vitamin()`
for bought ones, `make_all` for BOM, DXFs, exploded views and the assembly manual, and
`config_<target>.scad` for multiple configurations. Requirements read from
[`docs/usage.md`](https://github.com/nophead/NopSCADlib/blob/master/docs/usage.md):
OpenSCAD 2021.01+, Python 3.6+, **ImageMagick 7** (the scripts call the `magick` binary),
and the Python `colorama`, `markdown` and `codespell` modules.
→ everything in `scad/`, `docs/design-basis.md` §11

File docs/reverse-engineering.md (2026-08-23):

# Reverse-engineering the Onshape original

A 1.5 in prototype was drawn in Onshape and exported as
`Bender assembly.step` (AP242, millimetres). That file is the reference this model was
started from; it is **not** the specification. This document records what it actually
measures and, feature by feature, what carries over.

The STEP and everything derived from it live in `reference/`, which is gitignored: the
file is ~1.2 MB, the exploded parts and meshes are derived from it, and none of it belongs
in this repo's history. Regenerate with `reference/tools/explode.py`, which reads the
B-rep with OCCT and reports exact face and edge parameters — nothing here was scaled off a
screenshot.

---

## What it is

A manual swing-arm rotary-draw bender of the J D Squared / Pro-Tools pattern. Tube OD
**38.1 mm (1.5 in)** — every groove in the model is r = 19.05.

Onshape part names map onto the trade's vocabulary (see
[`design-basis.md`](design-basis.md) §1):

| Onshape name | trade name |
|---|---|
| `top_die` + `bottom_die` + `top_plate` + `bottom_plate` | forming die |
| `Die tubing locker` | U-strap / clamp |
| `Tube guide` | followbar / pressure die |
| `loop` | follower shoe on the outgoing leg |
| `fixed arm` | frame link |
| `mobile arm` | drive link |
| `spacer` | spacer |

## Stack (z, mm) — total 76.2 (3 in)

| z range | part |
|---|---|
| 0 – 6.35 | frame link (lower) |
| 6.35 – 12.70 | drive link (lower) |
| 12.70 – 19.05 | bottom_plate |
| 19.05 – 38.10 | bottom_die |
| 38.10 – 57.15 | top_die |
| 57.15 – 63.50 | top_plate |
| 63.50 – 69.85 | drive link (upper) |
| 69.85 – 76.20 | frame link (upper) |

Tube centreline plane z = 38.10, the die split plane. Plates and links are 6.35 mm
(1/4 in); each die half is 19.05 mm (3/4 in), so **die thickness = tube OD**.

## Forming die

- groove: half-round r = 19.05 cut in the outer rim, split on z = 38.10
- groove root circle r = **113.010** → tube **CLR = 132.06 mm**, i.e. **3.466 x OD**
- die outer r = 131.814; die plates r = **136.525** (5.375 in)
- arc span 221.7 deg
- clamp bolts: **20 x d8 on r = 95.25 (3.75 in)**, evenly spaced 10.9447 deg, symmetric
  about +Y, spanning +/-104 deg
- drive holes: **d20 at centre + 6 x d20 on r = 70.0**, spaced 36 deg
- the plates carry a 6.35-wide slot for the U-strap tongue

## Links (both 6.35 mm plate, 60 mm wide, all holes d20)

- **drive link**: pivot eye r30 at x = 0; holes at x = 0, 70, 315, 375; nose ending x = 400
- **frame link**: pivot eye r30 at x = 0, 45 deg dog-leg to a beam at y = 60 carrying
  **8 holes at 23.175 mm pitch, x = 88.758 .. 250.983**, then holes at x = 354.323 and
  399.323, same nose

## Small parts

- **followbar** 65 x 80 x 63.5 block; half-round r19.05 channel along y at local
  (x = 0, z = 31.75), relieved between y = 20..60; d20 pin hole at (46.35, 30)
- **follower shoe** half-round cradle r19.05 / OD 50.8, 40 mm long, arm out to a d20 pin
  hole 72 mm away
- **U-strap** 57.7 x 86.4 x 50.8 block, d20 pin hole, tapped cross hole d17.5, 6.35 tongue
  running in the die-plate slot, r2 fillets
- **spacer** washer OD 30 / ID 20 / t 4.05

## Hardware carried in the STEP

Both were measured off the McMaster CAD models embedded in the STEP, from the mesh rather
than the B-rep bounding box — the spline poles of the thread overstate the extent by 2 mm.
Both come out on exact imperial sizes, which is the check that the measurement is right.

- **McMaster 91236A849** hex head screw, **3/4-10 UNC x 3-1/2 in**: shank d 19.05 (3/4 in),
  hex 28.575 across flats (1-1/8 in) and 32.996 across corners, head 12.7 thick (1/2 in),
  thread minor d 15.75, overall 101.6 (4 in)
- **McMaster 98306A868** clevis pin, **3/4 in dia x 3-3/4 in long**: shank d 19.05, length
  under head 95.25 (3.75 in), head d 23.9776 x 6.604 thick, cotter hole d 3.9624 (5/32 in)
  centred 3.988 from the end

The clevis pin is registered in `scad/purchased/pins.scad`; the hex screw is registered
when the drive link that uses it is built.

---

## The four anomalies, resolved

Four things in the STEP could not be explained by the geometry alone. Research settled
three of them and two turned out to be **correct practice that would have been "fixed"
into a defect**.

### 1. Every pin hole is d20.0 metric on a d19.05 (3/4 in) pin — 0.95 mm of slop

**Keep, and make it explicit.** This is not slop, it is how the machine works. JD2 drills
its drive holes **1 in on a 7/8 in pin — 1/8 in (3.18 mm) oversize on purpose**, "to
provide easier pin installation", because the drive pin is moved by hand every few degrees
of bend [JD2-M32 p.7]. Tightening these holes would make the bender unusable.

What the original does not do is distinguish the fits: the frame pivot, which should be a
close running fit, has the same d20 hole as the index holes, which should be loose. The
model registers **pivot fit** and **index fit** separately.

### 2. The followbar channel is at x = 135.108; the die tangent line is at 132.06

3.048 mm (0.120 in) outboard. **Probably a real effect, drawn the wrong way.** A
production followbar's rear insert is deliberately **angled** relative to the tube axis to
support the tube just past the point of bend, and its grooves ride slightly *lower* than
the die's groove so it can rise under load rather than bind [JD2-M32 p.5]. A plain 3 mm
radial offset is neither of those. Treated as drafting slop for now; the real geometry is
a followbar drop and a rear-insert angle, both on the roadmap (`design-basis.md` §5).

### 3. CLR 132.06 mm = 5.199 in is round in neither system

**Discard.** No rule recovers it and it is not a radius anyone sells: Pro-Tools' 1-1/2 in
dies are 4-1/2, 5, 6 and 7 in [PROTOOLS-DIES]. It sits between two catalogue sizes. The
parametric model defaults to the smallest catalogued CLR at or above 3 x OD, which for
1-1/2 in tube is **4-1/2 in (114.3 mm)**.

For comparison against the original, 5.199 in is 3.466D — comfortably inside the 2.8–4.8D
band the whole catalogue occupies, so the prototype bends fine. It is just not a die you
can order.

### 4. The follower shoe and its pin are not coincident with any hole in either link

**Discard.** The shoe's cradle axis is 131.5 mm from the pivot against a 132.06 mm CLR,
and its pin lands at radius 103.6 where nothing else has a hole. Hand-placed, not mated.

---

## What the original contributes, in the end

The prototype is the reason this repo exists and it fixes the architecture: the stack
order, the split-die-plus-plates construction, the dog-leg frame link, the U-strap tongue
running in a plate slot, and 1.5 in as the size to check the parametric model against.

Its **numbers** are a starting point and mostly do not survive: the CLR is not orderable,
the pin fits are undifferentiated, the followbar is offset the wrong way, and the whole
thing is one fixed size. That is the expected outcome of a late-night prototype and is why
the model is being derived rather than transcribed.

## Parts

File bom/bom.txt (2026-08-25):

Vitamins:
       H   
       a   
 B     n  M
 a  D  d  a
 s  i  l  i
 e  e  e  n
  |  |  | 2|  2 Bolt hex head 5/16 in x 127 mm, with nut and washers, NO ORDER NUMBER - this row is a hole in the BOM
  |  |  | 1|  1 Bolt hex head 3/8 in x 38.1 mm, with nut and washers, NO ORDER NUMBER - this row is a hole in the BOM
  | 6|  |  |  6 Bolt hex head 3/8 in x 57.15 mm, with nut and washers, NO ORDER NUMBER - this row is a hole in the BOM
  |  |  | 4|  4 Bolt hex head 1/2 in x 44.45 mm, with nut and washers, NO ORDER NUMBER - this row is a hole in the BOM
  |  |  | 1|  1 Plate mild steel 1-3/4 in, blank 54.37 x 76.2 mm, faced to 44.45 mm
  |  |  | 1|  1 Plate mild steel 1-3/4 in, blank 57.55 x 76.2 mm, faced to 44.45 mm
  | 1|  |  |  1 Plate mild steel 1-3/4 in, blank 228.6 x 190.5 mm, faced to 44.45 mm
  |  | 2|  |  2 Pin clevis 5/16 in dia x 82.55 mm usable, NO ORDER NUMBER - this row is a hole in the BOM
  |  |  | 2|  2 Pin clevis 5/8 in dia x 57.15 mm usable, NO ORDER NUMBER - this row is a hole in the BOM
  |  |  | 1|  1 Pin clevis 3/4 in dia x 88.9 mm usable, seats on the base plate, 98306A868
  |  |  | 1|  1 Pin clevis 7/8 in dia x 82.55 mm usable, NO ORDER NUMBER - this row is a hole in the BOM
  |  |  | 1|  1 Pin clevis 7/8 in dia x 88.9 mm usable, seats on the base plate, NO ORDER NUMBER - this row is a hole in the BOM
  |  |  | 1|  1 Pin clevis 1-1/8 in dia x 88.9 mm usable, seats on the base plate, NO ORDER NUMBER - this row is a hole in the BOM
  |  | 2|  |  2 Plate mild steel 1/4 in, blank 2034.1 x 86.93 mm
  | 2|  |  |  2 Plate mild steel 1/4 in, blank 228.6 x 190.5 mm
 1|  |  | 1|  2 Plate mild steel 1/4 in, blank 368.73 x 210.75 mm
 1|  |  |  |  1 Plate mild steel 3/8 in, blank 171.45 x 171.45 mm
 1|  |  |  |  1 Plate mild steel 3/8 in, blank 416.59 x 258.61 mm
  |  | 2|  |  2 Tube 1/2 in OD x 0.065 in wall, mild steel, length 58.15 mm
  |  |  | 2|  2 Tube 1/2 in OD x 0.065 in wall, mild steel, length 71.85 mm
 1|  |  |  |  1 Tube 2-1/4 in OD x 0.120 in wall, mild steel, length 898.2 mm
  |  |  | 1|  1 Tube 1-1/2 in OD x 0.095 in wall, ASTM A513 Type 1 ERW mild steel, as-welded, length 600 mm

Printed:
  |  |  | 1|  1 clamp.stl
  |  |  | 1|  1 followbar.stl
  | 1|  |  |  1 forming_die.stl

CNC cut:
 1|  |  |  |  1 base.dxf
  | 2|  |  |  2 die_plate.dxf
  |  | 2|  |  2 drive_link.dxf
 1|  |  | 1|  2 frame_link.dxf
 1|  |  |  |  1 pedestal_foot.dxf

Assemblies:
  1 base_assembly
  1 die_assembly
  1 handle_assembly
  1 main_assembly

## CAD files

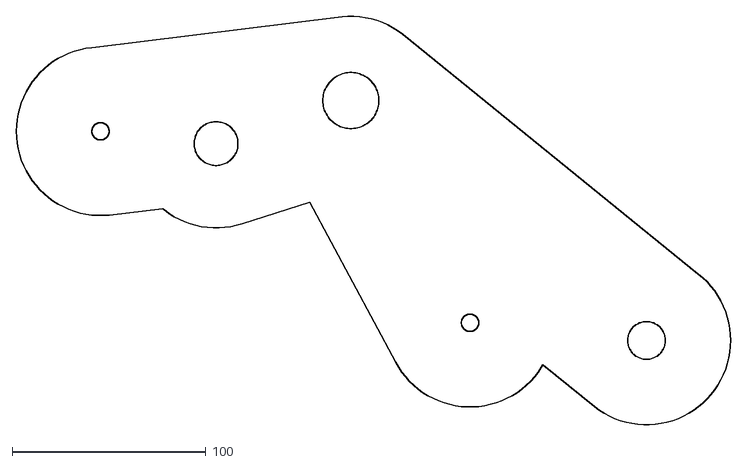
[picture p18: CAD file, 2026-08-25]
dxfs/frame_link.dxf
368.7 x 210.7

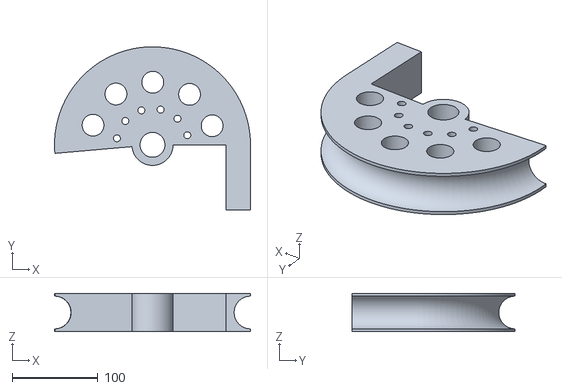
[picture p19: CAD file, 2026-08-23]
stls/forming_die.stl
228.6 x 190.5 x 44.5

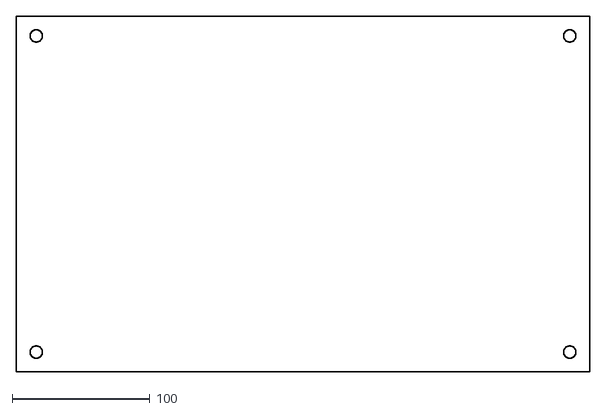
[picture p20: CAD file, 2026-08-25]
dxfs/base.dxf
416.6 x 258.6

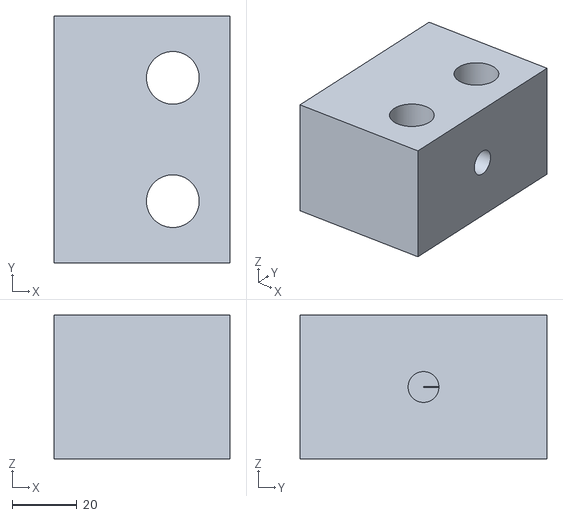
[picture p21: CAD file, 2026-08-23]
stls/clamp.stl
54.4 x 76.2 x 44.5

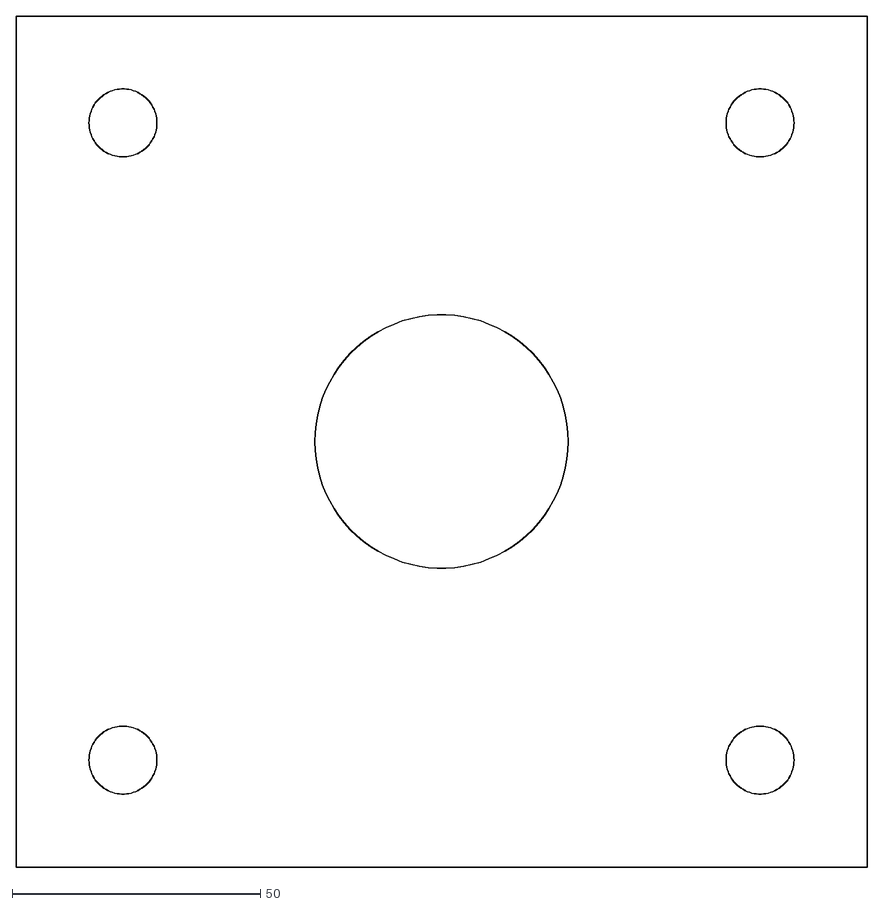
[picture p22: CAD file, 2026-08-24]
dxfs/pedestal_foot.dxf
171.4 x 171.4

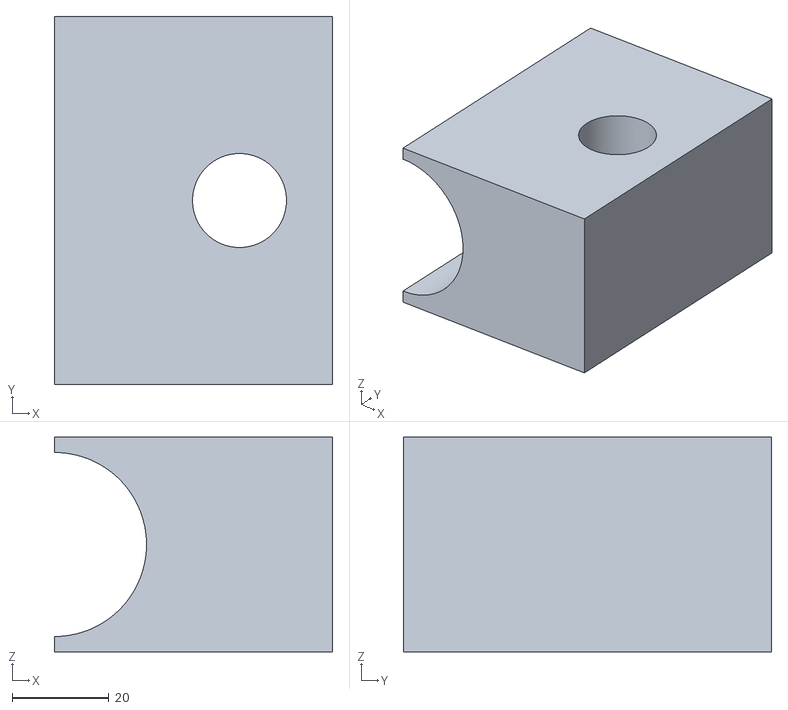
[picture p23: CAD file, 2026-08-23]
stls/followbar.stl
57.5 x 76.2 x 44.5

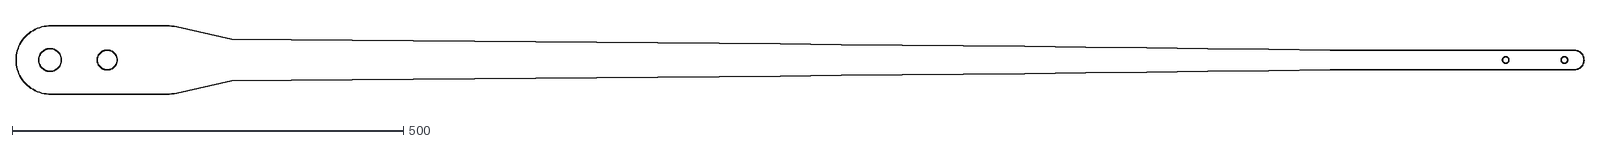
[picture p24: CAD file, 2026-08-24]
dxfs/drive_link.dxf
2003.1 x 86.9

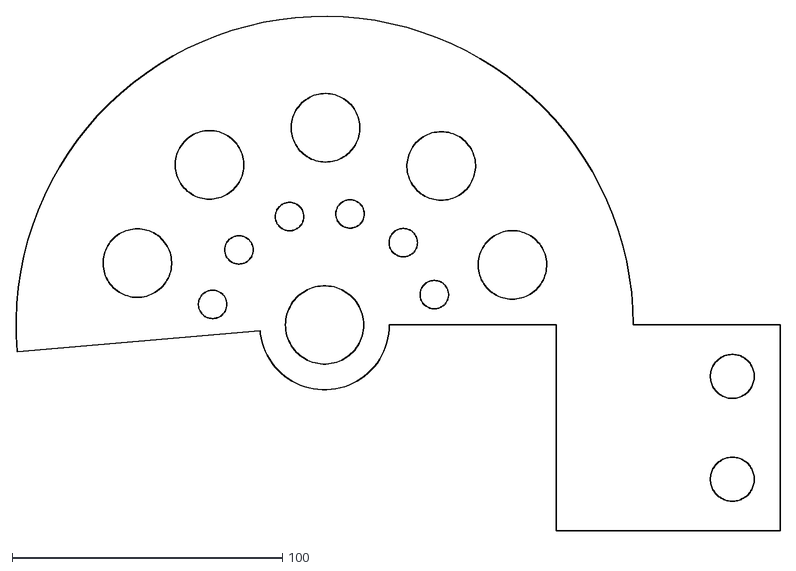
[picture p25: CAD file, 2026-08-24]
dxfs/die_plate.dxf
283.0 x 190.5

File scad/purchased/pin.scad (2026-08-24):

/**
 * @file pin.scad
 * @brief Accessors for the rows in pins.scad, and the pins they describe
 * @author Cameron K. Brooks
 * @copyright 2026
 * @description Drawn head-down at the origin with the shank running up +z, so a hole
 * pattern can place one without arithmetic. Length is passed in, not registered - it is
 * the stack the pin has to cross.
 *
 * ## Grip in, usable length out
 *
 * The caller passes the GRIP: how much stack the pin has to hold together. What gets
 * ordered is the USABLE LENGTH - head underside to the cotter hole - and that comes in
 * quarter-inch steps, because a clevis pin's holes are spaced a quarter inch apart
 * [MCMASTER-CLEVIS]. So the grip is rounded up, and the slack that leaves is reported
 * rather than hidden: it is up to a quarter inch of washers, and a builder who does not
 * know that assembles a joint that rattles.
 *
 * ## Every pin here drops in, head up, and nothing holds it
 *
 * That is not a simplification, it is what the reference machine does. Searched end to end,
 * the Model 32 manual contains no cotter, no clip, no snap ring and no retainer of any kind
 * on any pin [JD2-M32]. They are plain pins, dropped into vertical holes, held by gravity,
 * with one operating instruction covering the lot: "make sure all pins are completely
 * seated in their holes... failure to do this may cause damage to the bender links or worse
 * yet the operator may slip and fall" [JD2-M32 p.7].
 *
 * The reason it works is that every hole on this machine is VERTICAL. Nothing here ever
 * turns a pin upside down: the die rotates about a vertical axis, so a pin that is upright
 * at the start of a bend is upright at the end of it.
 *
 * The reason it MATTERS is that all of them come out. The frame pin is pulled to load a
 * die and to get the drive links in; the drive pin is pulled at every stroke; the lock pin
 * is lifted to release the die. A pin with a cotter on it is a pin you cannot pull, and the
 * manual's own assembly step depends on being able to: bolts hand tight, pins in, then
 * "tighten the nuts as tightly as possible, while insuring the two pins are perfectly
 * vertical and slide easily through their respective holes" [JD2-M32 p.1]. The pins are the
 * alignment gauge.
 *
 * ## The head goes on TOP, and on some pins it is the only thing holding them up
 *
 * `seat` records what is UNDER a pin, because the two cases are not equally forgiving:
 *
 * - **"base"** - the frame, followbar and lock pins sit over the base plate, and it is what
 *   they land on. The head is then a handle and a stop for the plate above, not a structural
 *   necessity.
 * - **"stack"** - the drive, U-strap and spacer pins hang in the stack with nothing beneath
 *   them, so the head IS what holds them up. A row with no head dimensions looked up draws
 *   as a bare shank, and that is honest: nothing is holding that pin, in the drawing or on
 *   the bench, until somebody looks the part up.
 *
 * Sets no $fn, so the resolution of the calling file carries through.
 */

include <NopSCADlib/core.scad>;

use <../utils/units.scad>

function pin_name(type)            = type[0];  //! Registry name
function pin_size(type)            = type[1];  //! Imperial size, the identity you order by
function pin_diameter(type)        = type[2];  //! Shank diameter, mm
function pin_head_diameter(type)   = type[3];  //! Head diameter, mm, or undef if unlooked-up
function pin_head_thickness(type)  = type[4];  //! Head thickness, mm, or undef
function pin_cotter_hole(type)     = type[5];  //! Cotter pin hole diameter, mm, or undef
function pin_cotter_from_end(type) = type[6];  //! Cotter hole centre to the pin's end, mm
function pin_part_no(type)         = type[7];  //! Order number, or undef if none is known

//! Whether this row describes something a second builder could actually order.
function pin_is_orderable(type) = !is_undef(pin_part_no(type));

//! Running clearance on the diameter for a pin that turns in its hole for the life of the
//! machine. REASONED, NOT CITED: no source read gives a fit for this joint, and the
//! consequence of getting it slightly loose is lost motion at the die rather than a
//! failure, so it is a machining allowance rather than a calculated fit.
pin_pivot_clearance = 0.4;

//! Clearance on the diameter for a pin that is pulled and repositioned by hand mid-bend,
//! as a FRACTION of the pin diameter.
//!
//! JD2 drills 1 in drive holes for a 7/8 in drive pin - 1/8 in oversize - "to provide
//! easier pin installation" [JD2-M32 p.7]. That is a real number for a real machine, and
//! it is stated as an absolute; it is carried here as the ratio it implies, 1/8 over 7/8,
//! because their bender is ONE size covering 1/2 to 2 in tube while this one scales. An
//! absolute 3.2 mm on the 6 mm drive pin a 3/8 in bender wants is not a clearance, it is
//! a slot.
pin_index_clearance_fraction = (1/8) / (7/8);

//! Hole diameter for a pin that turns in it.
function pin_pivot_hole(diameter) = diameter + pin_pivot_clearance;

//! Hole diameter for a pin that is indexed by hand.
function pin_index_hole(diameter) = diameter * (1 + pin_index_clearance_fraction);

//! The step a clevis pin's usable length comes in, mm.
//!
//! CATALOGUED: a clevis pin carries several cotter holes "spaced 1/4 inch apart", and which
//! one the cotter goes through is what sets the usable length [MCMASTER-CLEVIS]. So the
//! series is not a list of part numbers, it is an increment.
pin_length_step = inch(1/4);

//! The usable length to order for a pin that has to grip `mm` of stack.
function pin_usable_length(mm) = ceil(mm / pin_length_step - 1e-9) * pin_length_step;

//! How much the ordered pin overshoots the stack, mm - a washer stack, not a rounding
//! error. Never as much as one step.
function pin_slack(mm) = pin_usable_length(mm) - mm;

//! How far past the cotter hole a pin's own end runs, mm, where no row has been measured.
//!
//! REASONED, NOT CITED, and drawing only: nothing is sized from it and nothing is ordered by
//! it, because usable length is what a pin is bought by. Where the row HAS been looked up,
//! its measured cotter-hole-to-end is used instead - 3.99 mm on the 3/4 in pin, which is
//! what this stands in for.
pin_end_allowance = 3;

//! Whether a head-seated pin's row knows what its head is - which is the only thing keeping
//! that pin from dropping through, so it is worth being able to ask.
function pin_head_is_known(type) = !is_undef(pin_head_diameter(type));

//! Draw a pin gripping `grip` mm of stack, shank running up from z = 0, and bill it at the
//! usable length you would order plus whatever holds it in.
//!
//! `seat` is what stops it dropping: "base" for a pin that lands on the base plate and is
//! therefore plain and headless, "head" for one that hangs in the stack on its own head,
//! which is then drawn on TOP. `retainer` is what stops it lifting - "cotter", "clip", or
//! "none" for a pin that is meant to come out. See the file header.
//!
//! A head-seated row with no head geometry looked up yet draws as a bare shank. That is
//! honest rather than convenient: nothing is holding that pin up, in the drawing or on the
//! bench, until somebody looks the part up.
module pin(type, grip, seat = "stack") {
    d      = pin_diameter(type);
    headed = pin_head_is_known(type);
    length = pin_usable_length(grip);

    // The key before the colon is the BOM's own identity for this part and stays in
    // millimetres in both systems, the way a part number would - it is what groups
    // identical items, not something anybody measures. Only the human half converts.
    vitamin(str("pin(", pin_name(type), ", ", round(length), "): Pin clevis ",
                pin_size(type), " x ", fmt_length(length), " usable",
                seat == "base" ? ", seats on the base plate" : "",
                pin_is_orderable(type)
                    ? str(", ", pin_part_no(type))
                    : ", NO ORDER NUMBER - this row is a hole in the BOM"));

    color("silver") {
        // On TOP. Every pin here goes in head up: on a stack-seated pin the head is the
        // only thing holding it, and on a base-seated one it is the handle you pull it out
        // by and the stop that keeps the plate above from lifting.
        if (headed)
            translate_z(length)
                cylinder(d = pin_head_diameter(type), h = pin_head_thickness(type));

        cylinder(d = d, h = length + (headed ? 0 : pin_end_allowance));
    }
}

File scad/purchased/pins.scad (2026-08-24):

//
// Clevis pins - the pivots the whole machine turns on.
// DO NOT FORMAT THIS FILE, it is manually spaced out for readability.
//
// This is a DIAMETER SERIES, because that is what pin sizing produces: a required diameter
// from shear and bending, rounded up to something you can buy. Length is not registered -
// it is the stack the pin has to cross, which the assembly knows and the catalogue does
// not, so pin() takes it as an argument.
//
// Only one row carries an order number and head geometry, and it is the one that was
// MEASURED off the McMaster CAD model embedded in the prototype STEP. The rest carry undef
// for both, deliberately: an undef part number reaches the BOM as a hole in it, and a
// plausible invented number sitting beside a real one inherits its authority. Same for the
// head - a pin drawn with a fabricated head looks as specified as a pin drawn with a real
// one. pin_is_orderable() is what notices, and pin() draws a bare shank where it must.
//
// Filling this table in is a shopping trip, not a modelling problem.
//
include <NopSCADlib/core.scad>; // inch()

//! Build a pin row. `diameter` in mm; everything after it is optional and stays undef
//! until somebody looks the part up.
function ClevisPin(name, size, diameter, head_diameter = undef, head_thickness = undef,
                   cotter_hole = undef, cotter_from_end = undef, part_no = undef) =
    [name, size, diameter, head_diameter, head_thickness, cotter_hole, cotter_from_end,
     part_no];

//                                                                   dia         head dia  head t  cotter      from end  part no
pin_0p1875in = ClevisPin("pin_0p1875in", "3/16 in dia", inch(3/16));
pin_0p250in  = ClevisPin("pin_0p250in",  "1/4 in dia",  inch(1/4));
pin_0p3125in = ClevisPin("pin_0p3125in", "5/16 in dia", inch(5/16));
pin_0p375in  = ClevisPin("pin_0p375in",  "3/8 in dia",  inch(3/8));
pin_0p4375in = ClevisPin("pin_0p4375in", "7/16 in dia", inch(7/16));
pin_0p500in  = ClevisPin("pin_0p500in",  "1/2 in dia",  inch(1/2));
pin_0p625in  = ClevisPin("pin_0p625in",  "5/8 in dia",  inch(5/8));
pin_0p750in  = ClevisPin("pin_0p750in",  "3/4 in dia",  inch(3/4),  23.9776,  6.604,  inch(5/32), 3.988, "98306A868");
pin_0p875in  = ClevisPin("pin_0p875in",  "7/8 in dia",  inch(7/8));
pin_1p000in  = ClevisPin("pin_1p000in",  "1 in dia",    inch(1));
pin_1p125in  = ClevisPin("pin_1p125in",  "1-1/8 in dia",inch(1 + 1/8));
pin_1p250in  = ClevisPin("pin_1p250in",  "1-1/4 in dia",inch(1 + 1/4));
pin_1p375in  = ClevisPin("pin_1p375in",  "1-3/8 in dia",inch(1 + 3/8));
pin_1p500in  = ClevisPin("pin_1p500in",  "1-1/2 in dia",inch(1 + 1/2));

pins = [pin_0p1875in, pin_0p250in, pin_0p3125in, pin_0p375in, pin_0p4375in, pin_0p500in,
        pin_0p625in, pin_0p750in, pin_0p875in, pin_1p000in, pin_1p125in, pin_1p250in,
        pin_1p375in, pin_1p500in];

// The last two rows were added when the frame pin's span was corrected to include the die
// plates. At 2 in that asked for 32.0 mm and the series stopped at 31.75 - a shortfall of
// nine tenths of a percent, which is well inside the conservatism of taking AISC's TENSION
// allowable for a solid round in bending. The series was extended rather than the
// allowable relaxed: a bigger pin is cheap and the margin is not the place to find savings.

//
// Pin material. The prototype's pin is McMaster's "1004-1045 carbon steel", which is a
// RANGE of grades rather than a grade - the supplier may ship anything in it. The anchor
// registered here is AISI 1018 cold drawn, 370 MPa yield, from a mill data sheet
// [MW-1018]; 1004 sits below that and is not documented here.
//
// So this number is only as good as the pin you actually buy. Order to a stated grade, or
// re-check the margin against whatever turns up. It is registered as one number rather
// than a band because only one end of the band has a source.
//
pin_material_yield = 370;

//! The smallest registered pin at least `d` mm across, or `undef` if the series does not
//! reach it. Lives beside the list because a default argument is evaluated in the scope of
//! the file that defines the function, and pin.scad cannot see `pins`.
function pin_smallest_at_least(d, from = pins) =
    let (above = [for (p = from) if (pin_diameter(p) >= d - 0.01) pin_diameter(p)])
        len(above) == 0 ? undef
                        : [for (p = from) if (pin_diameter(p) == min(above)) p][0];

use <pin.scad>; // pin() draws the pin these rows describe

//! The row called `name`, for a caller that has a string rather than a row.
//!
//! This is how the OpenSCAD Customizer reaches the registry. Customizer parameters may only
//! be LITERALS - a string, a number, a boolean - so a configuration cannot hold a row; it
//! holds the row's name and looks it up here. Lives beside the list for the usual reason: a
//! default argument is evaluated in the scope of the file that defines the function.
//!
//! Asserts rather than returning undef. A name that is not in the registry is a typo or a
//! stale dropdown, and undef would travel a long way from here before it surfaced.
function pin_by_name(name, from = pins) =
    let (hit = [for (r = from) if (pin_name(r) == name) r])
        assert(len(hit) == 1, str("no such pin in the registry: ", name))
        hit[0];

//! Every registered name, in registry order - what a Customizer dropdown has to offer.
function pin_names(from = pins) = [for (r = from) pin_name(r)];

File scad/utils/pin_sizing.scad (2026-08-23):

/**
 * @file pin_sizing.scad
 * @brief What diameter a pin has to be, from the load and the stack it crosses
 * @author Cameron K. Brooks
 * @copyright 2026
 * @description Draws nothing. Every pin in this machine is loaded in double shear - a
 * central member between two outer ones - and the two ways it can fail are checked
 * separately because THEY DO NOT AGREE. On this machine bending governs by a factor of
 * about two and a half, and sizing on shear alone gives a pin less than half the diameter
 * the reference machines use.
 *
 * ## The bending model
 *
 * The pin is taken as a simply supported beam: the central member's load `F` as a point
 * load at midspan, each outer member reacting `F/2` at its own centroid. The span between
 * those centroids is `t_centre + t_outer`, so
 *
 *     M = F (t_centre + t_outer) / 4
 *
 * That is the standard conservative treatment of a clevis pin - it ignores that the load
 * is distributed across each member's thickness, which is why it is conservative. A pin
 * with no clearance and perfectly rigid members would see less.
 *
 * ## Allowables
 *
 * AISC allowable stress design, as stated in the Engineering Journal: "tension,
 * Ft = 0.6Fy, and that in shear, Fv = 0.4Fy" [AISC-GOEL]. Those fractions carry their own
 * factor of safety against the von Mises shear yield of ~0.6Fy.
 *
 * Bending uses the TENSION allowable, 0.6Fy. AISC allows more for a solid round section;
 * taking the tension figure is deliberately conservative and costs a few percent on the
 * diameter.
 *
 * Bearing on the plates is REPORTED rather than allowed for. No bearing allowable was
 * found in a source that could be read, and inventing one would put a fabricated number
 * in the load path - see docs/design-basis.md.
 *
 * Sets no $fn.
 */

include <NopSCADlib/core.scad>;

//! AISC allowable shear as a fraction of yield [AISC-GOEL].
pin_allowable_shear_fraction = 0.4;

//! AISC allowable tension as a fraction of yield [AISC-GOEL], used here for bending too.
pin_allowable_bending_fraction = 0.6;

//
// Stresses in a pin that has already been chosen. These are what get reported.
//

//! Shear stress, MPa, in a pin of `d` mm carrying `force_N` across two shear planes.
function pin_shear_stress(force_N, d) = 2 * force_N / (PI * d * d);

//! Bending moment, N.mm, in a pin crossing a `t_centre` member between two `t_outer` ones.
function pin_bending_moment(force_N, t_centre, t_outer) =
    force_N * (t_centre + t_outer) / 4;

//! Bending stress, MPa, in a pin of `d` mm.
function pin_bending_stress(force_N, d, t_centre, t_outer) =
    32 * pin_bending_moment(force_N, t_centre, t_outer) / (PI * pow(d, 3));

//! Bearing stress, MPa, of a pin of `d` mm on a member of `t` mm carrying `force_N`.
function pin_bearing_stress(force_N, d, t) = force_N / (d * t);

//
// Diameters those stresses imply.
//

//! Diameter, mm, at which the shear allowable is exactly reached.
function pin_diameter_for_shear(force_N, yield_MPa) =
    sqrt(2 * force_N / (PI * pin_allowable_shear_fraction * yield_MPa));

//! Diameter, mm, at which the bending allowable is exactly reached.
function pin_diameter_for_bending(force_N, t_centre, t_outer, yield_MPa) =
    pow(32 * pin_bending_moment(force_N, t_centre, t_outer)
            / (PI * pin_allowable_bending_fraction * yield_MPa), 1/3);

//! The diameter the pin actually has to be: whichever failure mode governs.
function pin_required_diameter(force_N, t_centre, t_outer, yield_MPa) =
    max(pin_diameter_for_shear(force_N, yield_MPa),
        pin_diameter_for_bending(force_N, t_centre, t_outer, yield_MPa));

//! Which mode governs, as a name rather than a flag.
function pin_governing_mode(force_N, t_centre, t_outer, yield_MPa) =
    pin_diameter_for_bending(force_N, t_centre, t_outer, yield_MPa)
        >= pin_diameter_for_shear(force_N, yield_MPa) ? "bending" : "shear";

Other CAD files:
scad/custom/drive_link.scad
scad/custom/base.scad
scad/custom/clamp.scad
scad/custom/die_lock.scad
scad/custom/die_plate.scad
scad/custom/followbar.scad
scad/custom/forming_die.scad
scad/custom/frame_link.scad
scad/custom/pedestal.scad
scad/custom/sliced_die.scad
scad/purchased/bolt.scad
scad/purchased/bolts.scad
scad/purchased/plate.scad
scad/purchased/plates.scad
scad/purchased/structural_tube.scad
scad/purchased/structural_tubes.scad
scad/purchased/tube.scad
scad/purchased/tube_material.scad
scad/purchased/tube_materials.scad
scad/purchased/tubes.scad
scad/tube_bender.scad
scad/utils/bend.scad
scad/utils/clr_catalogue.scad
scad/utils/layout.scad
scad/utils/units.scad
scad/utils/weld.scad
scripts/registry_options.scad

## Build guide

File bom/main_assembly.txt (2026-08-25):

main_assembly:
Vitamins:
  2 Bolt hex head 5/16 in x 127 mm, with nut and washers, NO ORDER NUMBER - this row is a hole in the BOM
  1 Bolt hex head 3/8 in x 38.1 mm, with nut and washers, NO ORDER NUMBER - this row is a hole in the BOM
  4 Bolt hex head 1/2 in x 44.45 mm, with nut and washers, NO ORDER NUMBER - this row is a hole in the BOM
  1 Plate mild steel 1-3/4 in, blank 54.37 x 76.2 mm, faced to 44.45 mm
  1 Plate mild steel 1-3/4 in, blank 57.55 x 76.2 mm, faced to 44.45 mm
  2 Pin clevis 5/8 in dia x 57.15 mm usable, NO ORDER NUMBER - this row is a hole in the BOM
  1 Pin clevis 3/4 in dia x 88.9 mm usable, seats on the base plate, 98306A868
  1 Pin clevis 7/8 in dia x 82.55 mm usable, NO ORDER NUMBER - this row is a hole in the BOM
  1 Pin clevis 7/8 in dia x 88.9 mm usable, seats on the base plate, NO ORDER NUMBER - this row is a hole in the BOM
  1 Pin clevis 1-1/8 in dia x 88.9 mm usable, seats on the base plate, NO ORDER NUMBER - this row is a hole in the BOM
  1 Plate mild steel 1/4 in, blank 368.73 x 210.75 mm
  2 Tube 1/2 in OD x 0.065 in wall, mild steel, length 71.85 mm
  1 Tube 1-1/2 in OD x 0.095 in wall, ASTM A513 Type 1 ERW mild steel, as-welded, length 600 mm

Printed:
  1 clamp.stl
  1 followbar.stl

CNC cut:
  1 frame_link.dxf

Assemblies:
  1 base_assembly
  1 die_assembly
  1 handle_assembly

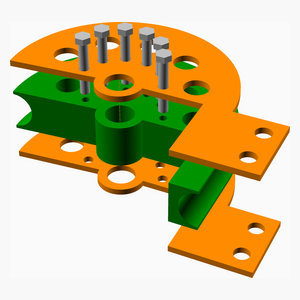
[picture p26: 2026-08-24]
assemblies/die_assembly_tn.png

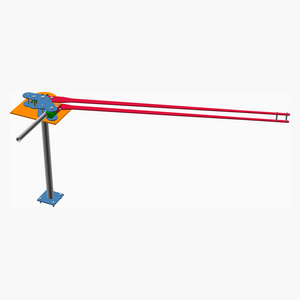
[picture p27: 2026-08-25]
assemblies/main_assembled_tn.png

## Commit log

2026-08-23 docs: record the design basis, its sources and the prototype teardown
    Establishes what the machine's numbers rest on before any geometry
    exists: the 3 x OD minimum centreline radius for mandrel-less bending,
    the 1/8 to 2 in size band, yield registered as the band ASTM A513
    gives rather than a midpoint, and a handle length derived from the
    490 N operator pull ceiling in the FAA human factors standard.
    Also records what the Onshape prototype actually measures. Two of its
    four apparent defects are correct practice - drive holes are drilled
    oversize on purpose, and a forming die groove is profiled so the tube
    does not fully seat - and would have been 'fixed' into real defects.
2026-08-23 build: scaffold the model on nopscadlib with a tube registry
    Sets up the gate and the spine the rest of the machine hangs off.
    check-scad evaluates every scad file in both directions: entry files
    must emit geometry, everything else must emit none, so a registry that
    draws its own example fails rather than leaking into every consumer.
    A failing assert exits 0 in OpenSCAD, so the recipe greps stderr for
    ERROR and uses file size as the backstop.
    NopSCADlib's BOM and assembly machinery is used as intended, so
    readme.md is generated from the description block in tube_bender.scad
    and README.md is removed - two files differing only in case is a trap.
    utils/bend.scad draws nothing. It reports wal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
    [bend.scad, bom.csv, tube.scad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]
2026-08-23 feat(registries): add the clr catalogue, plate and pin stock
    The default centreline radius now comes from the radii the trade
    actually sells at or above the 3 x OD floor, rather than from a
    number typed into the config.
    check-sizes walks the whole tube registry, because check-scad renders
    each file once at its defaults and a departure that only fires at one
    end of the range is never evaluated. It fails both ways: an unexpected
    departure is a regression, and an expected one that stopped firing
    means the list has gone stale.
    It earned its keep immediately, finding two things:
    - the 3 x OD test compared a ratio against a whole number, so an inch
    conversion landing on 2.99999 reported a dep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
    [bend.scad, clr_catalogue.scad, pin.scad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]
2026-08-23 feat(die): derive the forming die from the tube, CLR and pins
    The die is a grooved sector with a tangent clamp tail, a pivot hub and a
    drive-hole circle. Nothing about it is a remembered dimension: thickness
    is the tube OD plus a land, outer radius is the CLR and cannot be
    anything else, arc is the bend plus overbend, tail is the clamp's grip
    length, and the drive circle is as large as the material between the
    groove root and the hole allows. Whether drive holes fit at all is
    derived rather than assumed. At the 1-1/2 in check size it returns five
    drive holes, which is what JD2 drills.
    Two corrections came out of building it.
    The clamp length was 3 x OD, taken from a summary of a trade arti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
    [bend.scad, bom.csv, forming_die.scad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]
2026-08-23 feat(links): derive the pins from load and add the frame and drive links
    Closes the loop Phase 2 left open. Every pin is now sized from the
    force it carries and the stack it crosses, and the two links from the
    section each needs at its worst hole.
    Bending governs every pin, by more than a factor of two over shear.
    Sizing on shear alone gives the 1-1/2 in machine a 3/8 in drive pin
    where it needs 7/8 in. Allowables are AISC ASD, Ft = 0.6Fy and
    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
    [bend.scad, bom.csv, drive_link.scad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]
2026-08-23 feat(base): anchor the machine and merge the handle into the drive link
    The drive link now runs the full handle length and the pair of them is
    the handle. A separate handle member is worse rather than merely
    different: the moment at a handle's root is the full bending moment
    whatever its length, so a bolted-on handle needs a root section as big
    as the link's, plus a joint that carries it, plus that joint to fit.
    At 1-1/2 in the smallest tube whose bore clears the link pair weighs
    the same as the plate pair it would replace.
    The base went through two designs. The first ran the drive torque out
    through two anchor bolts on the frame link's own axis, and the size
    sweep failed it at both ends: a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
    [base.scad, base.stl, bend.scad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]
2026-08-23 feat(followbar): add the pressure die and check the drive link's sweep
    The followbar caps the half of the tube the forming die does not, a
    station downstream of the die's tail, and is pinned to the frame links.
    It closes the placeholder the frame link had carried since Phase 3.
    Where its pin sits was a guess - one tube diameter outboard, on the
    prototype's precedent - because the part it belonged to did not exist.
    Derived, it is 19 mm closer in, which takes the frame link's moment
    from 815 to 757 N.m. The guess was not wildly wrong, and it was wrong.
    The followbar is only as tall as the die, because the drive links
    occupy the bands either side and sweep every radius. Its pin has to
    cross t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
    [base.scad, base.stl, bend.scad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]
2026-08-23 feat(clamp): add the die plates and the clamp they exist for
    The clamp holds the tube to the die while the die drags it round, and
    its mounting could not be solved on the die alone. It has to sit
    outboard of the tube where the tail has no material, be removable so
    multi-bend parts stay possible, avoid the bands either side of the die
    because the drive links sweep every radius, and it cannot reach
    inboard past the tube or through 3.2 mm of land.
    A plate on each face of the die satisfies all four. It fits the gap
    between the die and the drive links, and its tail overhangs the tube -
    reaching r 169 mm past the tube's outer surface at 133 mm - which is
    the only material anywhere the clamp can p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
    [bend.scad, bom.csv, clamp.scad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]
2026-08-23 feat(pedestal): taper the drive links and add a post to stand on
    The drive link is now tapered rather than constant width. Its moment
    falls off all the way from the drive hole to the handle's end, so a
    constant section was carrying about half again the steel it needed:
    15.6 kg for the pair becomes 8.7 kg, tapering 77 mm to 25 mm.
    The taper is drawn in steps, and each step carries the width required
    one position further IN. The requirement goes as the square root of
    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
    [bom.csv, drive_link.scad, drive_link.stl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]
2026-08-23 feat(die): add a sliced die that flat-cut plates can make
    Same die, different realisation, behind the same interface. Every
    dimension comes from the functions in forming_die.scad - arc, hub,
    tail, drive circle, groove root - so nothing downstream can tell which
    one it is bolted to, and die_style picks.
    The groove is a half-round and near its edges its surface runs almost
    parallel to the die's axis, so no horizontal slicing can follow it. A
    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
    [sliced_die.scad, tube_bender.scad]
2026-08-23 docs: report the operating cycle and scope the ratchet
    Six strokes of 1.22 m at the handle's end for a 180 degree bend, with
    the drive pin coming out between each. The cycle is now reported at
    every size so the cost of having no ratchet is visible rather than
    discovered on the bench.
    The ratchet is not built, and the stroke length is the lesser half of
    why it would be. The real problem is that nothing holds the die while
    the drive pin is out, so the tube springs back between strokes. JD2
    solves it with a lock pin that drops into the die's drive holes from
    the frame link.
    That pin has the clamp's problem again: to reach the die it must cross
    the drive links' band, and the drive links sweep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
    [bend.scad, forming_die.scad, tube_bender.scad]
2026-08-23 fix(bend): model the drive link's band, not its whole sweep
    The drive link is indexed: it engages a hole, pulls one pitch, and swings
    back to where it started while the die carries the next hole into place.
    It never leaves a band one pitch wide. The model had it sweeping the
    whole bend, which made the mechanism look like solid obstruction at
    every angle and put a die lock out of reach.
    Three defects fell out of the same mistake:
    - bend_strokes() computed ceil(arc / pitch) with no reference to how
    many drive holes existed. Each hole is used once, so n holes give n
    strokes and n x pitch degrees - and the shortfall comes out of the
    last stroke, not an extra one. At 1-1/2 in it reported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
    [bend.scad, tube_bender.scad]
2026-08-23 fix(pins): size every pivot on the span it actually crosses
    The central member of a pivot joint here is the die AND its plates. The
    plates are bolted to the die's faces, carry the same pivot bore and the
    same drive holes, and turn with it, so a pin through the die is a pin
    through all three. The model took the die alone, understating the span
    by two plate thicknesses - 12.7 mm at 1-1/2 in.
    Bending governs every pin on this machine, so that is not a rounding
    error. The frame pin steps up a size at 1-1/2 in and at 2 in; the drive
    pin steps up at 2 in.
    layout_central_thickness() states the fact once, beside the stack it is
    a fact about. The U-strap pin keeps the die's thickness and gets a not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
    [layout.scad, pins.scad, tube_bender.scad]
2026-08-23 refactor(base): drop a dead anchor-radius helper
    base_nominal_anchor_radius() sized a first bolt against a nominal inset
    before the real one was known. base_anchor_bolt() stopped needing it
    when the two-pass sizing was replaced by a direct filter, and it was
    left behind.
    It was also broken: it called base_anchor_radius() with four arguments
    where the signature takes five, so the inset arrived as undef and the
    whole thing returned undef. Nothing called it, so nothing noticed - and
    neither gate can see a function no caller reaches.
    AGENTS.md cited it as the example of exporting the calculation rather
    than the constant. Points at forming_die_drive_pitch() instead, which
    is live.
    [base.scad]
2026-08-23 fix(die): remove the U-strap hole nothing goes through
    The die carried a drilled-through hole in its tail for a U-strap pin,
    left over from the design that pinned the clamp INTO the die. That
    design is gone - section 15 works through why the clamp cannot reach
    the die at all, and it pins to the die plates instead, whose tails
    overhang the tube where nothing else can. The assembly places its clamp
    pins at die_plate_clamp_pins(); nothing has ever been placed in the
    die's hole.
    The pin went and the hole did not, and the tail stayed sized to clear
    it: 63.5 mm deep at 1-1/2 in where 28.6 carries the groove and a web.
    Same fault as the drive link that drew a hole for a die with no drive
    holes, fo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
    [base.stl, bom.csv, die_plate.scad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]
2026-08-23 feat(lock): hold the die against springback between strokes
    Nothing held the die while the drive pin was out, so the tube sprang
    back before it could be re-pinned and every stroke gave back part of
    what the last one gained. This is the die lock JD2 fits, derived rather
    than copied.
    Where it goes is exact, not chosen. Holes sit at inset + i x pitch, and
    stroke k ends with the die turned k x pitch, so hole n-k is then at
    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
    [bom.csv, die_lock.scad, frame_link.scad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]
2026-08-23 fix(bend): check where the drive band is, not just that it fits
    The sweep departure asked whether one stroke would fit in the sector the
    followbar leaves. That was the right question while the band's position
    was undecided. It is decided now - each stroke starts where the drive
    link picks up a hole, which at the start of a bend is the first hole's
    own angle - so the check can ask whether the band actually overlaps the
    followbar rather than whether there was room for it somewhere.
    Overlap is taken on arc midpoints against the sum of the half-widths.
    Comparing endpoints on a circle needs a case for every way the pair can
    wrap; midpoints need none.
    Verified it fires: an artificial followbar a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
    [bend.scad, tube_bender.scad]
2026-08-24 feat(registries): look a row up by its name
    Every registry row has carried a name accessor since the beginning and
    nothing could ever go the other way. Adds *_by_name() and *_names() to
    all five.
    This is what the OpenSCAD Customizer needs. A Customizer parameter may
    only be a literal - a string, a number, a boolean - so a configuration
    cannot hold a registry row. It holds the row's name, and this turns it
    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
    [bolts.scad, pins.scad, plates.scad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]
2026-08-24 feat(config): make the model drivable from the Customizer
    Nothing that mattered was selectable. The Customizer only picks up
    variables in the main file whose value is a LITERAL, and every knob
    worth turning was an identifier or an expression:
    tube = tube_1p500x0p095; a row, invisible
    drive_plate = plate_0p250in; invisible
    clr = bend_default_clr(tube); invisible
    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
    [registry_options.scad, tube_bender.scad]
2026-08-24 docs: do not write a brace in the rule about braces
    The configuration block explains that a Customizer parameter has to
    appear before the first opening brace, and wrote the character to say
    so. Comments are lexed away before anything looks for syntax elements,
    so it cannot matter - but a rule that appears to break itself is worth
    one edit to remove the question.
    [tube_bender.scad]
2026-08-24 feat(units): report and bill of materials in metric or imperial
    The model selected in imperial and read out in millimetres. This adds a
    units toggle, and it moves the whole system rather than only lengths -
    length, force, moment, stress and mass together. Inches with newtons is
    harder to check than either on its own: you cannot carry a sanity
    calculation across mixed units in your head.
    Nothing calculated changes. The derivation stays in mm, N and MPa, and
    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
    [base.scad, bend.scad, bolt.scad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]
2026-08-24 feat(fabrication): export the flat parts as DXF cut files
    Seven of the made parts are a 2D outline in plate - both links, both die
    plates, the base and the pedestal foot - and the model emitted them only
    as STL, which no cutting shop can quote from.
    Each flat part's file now yields a <part>_2D() profile and stops there;
    the extrusion belongs to whoever places it. routed_plate() places one:
    it names the part on the BOM, declares the DXF, extrudes the profile for
    the assembly view and colours it. NopSCADlib imports the exported file
    when it poses the assembly, so the manual's pictures are drawn from the
    cut files themselves and the two cannot drift apart quietly.
    The BOM gains a "CNC cut" se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
    [base.dxf, base.scad, base.stl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]
2026-08-24 feat(weld): size the three welded joints instead of naming them
    The lower frame link to the base plate, and the pedestal post to its
    foot and to the base plate above it. Between them they carry everything
    the machine sheds into the world, and every other load path here is
    sized from a stress and an allowable while these were a sentence in a
    comment.
    Weld as a line: a fillet's strength goes with its length, so a group is
    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
    [base.scad, pedestal.scad, tube_bender.scad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]
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2026-08-24 fix(pins): put every pin in head up, and take the retainers off
    The frame pin and the followbar pin had their heads inside the base
    plate. Both were placed at the lower frame link's underside, head down,
    and that link is welded flat to the plate, so the head sat entirely
    within its thickness. It was invisible because the 1-1/8 in row has no
    head geometry looked up; the one row that has been measured draws its
    head, and its head was in the plate.
    The candidates were a headless pin bottoming on the plate, a through-bolt
    with a nut underneath, or clearance holes for the heads. It was settled
    by reading what the machine this one is modelled on does, which is a
    source the project already cites a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
    [bom.csv, pin.scad, tube_bender.scad]
2026-08-25 feat(frame): tie the frame links together, and derive where they can go
    Section 14 deleted the frame bolts on three reasons. Two were right. The
    middle one - that the pair is already joined by the frame pin and the
    followbar pin - assumed those pins JOIN the frame. They are plain loose
    drop-in pins: they locate it. Nothing joined it, so the upper frame link
    was a plate resting on three pin heads and pulling one to change a die
    took it off with them.
    The job the reference machine's frame bolts do is not reacting the drive
    torque - which is what section 14 sized them for and rightly failed at -
    it is clamping the two links to a fixed gap through a length of tube.
    That is why a tie here is a b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
    [base.dxf, base.scad, bom.csv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]
2026-08-25 fix(base): only bolt the base down where there is something to bolt to
    On a pedestal build the post is welded to the underside of the base plate
    and there is nothing else beneath it, so the four anchor bolts at the
    plate's corners were drawn and billed going down into thin air. The
    torque leaves a pedestal through the foot bolts instead.
    The holes stay in the plate whichever mount it ends up on - it is one cut
    part and which stand it lands on is not the cutter's business - and the
    report still checks them, now saying plainly that they are the bench
    mount's.
    [base.scad, bom.csv, tube_bender.scad]
